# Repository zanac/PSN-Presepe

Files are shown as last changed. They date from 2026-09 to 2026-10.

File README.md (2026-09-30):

# PSN-Presepe

## Demo online Wokwi

▶️ [Apri la simulazione interattiva PSN-Presepe su Wokwi](https://wokwi.com/projects/476035349322038273)

La demo permette di provare direttamente dal browser il ciclo giorno/notte, le strisce RGB, il cielo stellato, OLED e comandi senza hardware reale.

Controller basato su Arduino Mega 2560 per la gestione modulare di un presepe a 12 V.

**Italiano** | [English](README_EN.md)

## Mockup della centralina

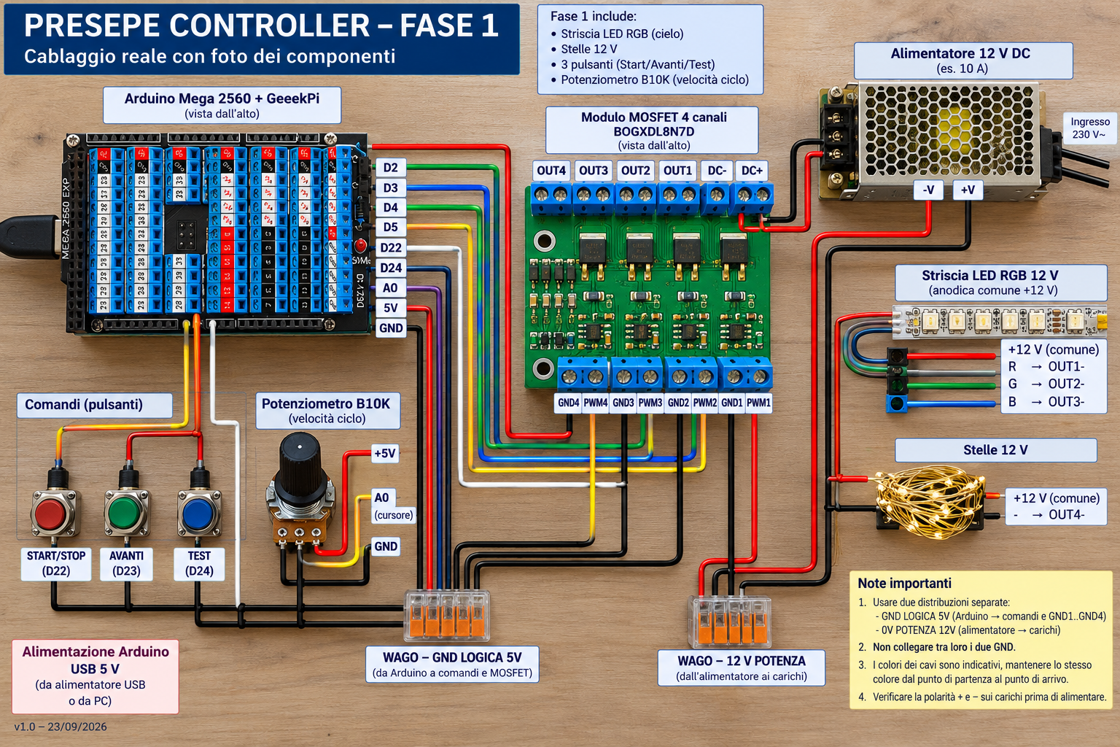
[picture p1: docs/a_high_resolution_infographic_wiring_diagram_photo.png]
Mockup centralina PSN-Presepe


> Mockup concettuale della disposizione della centralina. Per i collegamenti elettrici fare riferimento agli schemi vettoriali presenti nella cartella `docs/`.

## Schema elettrico

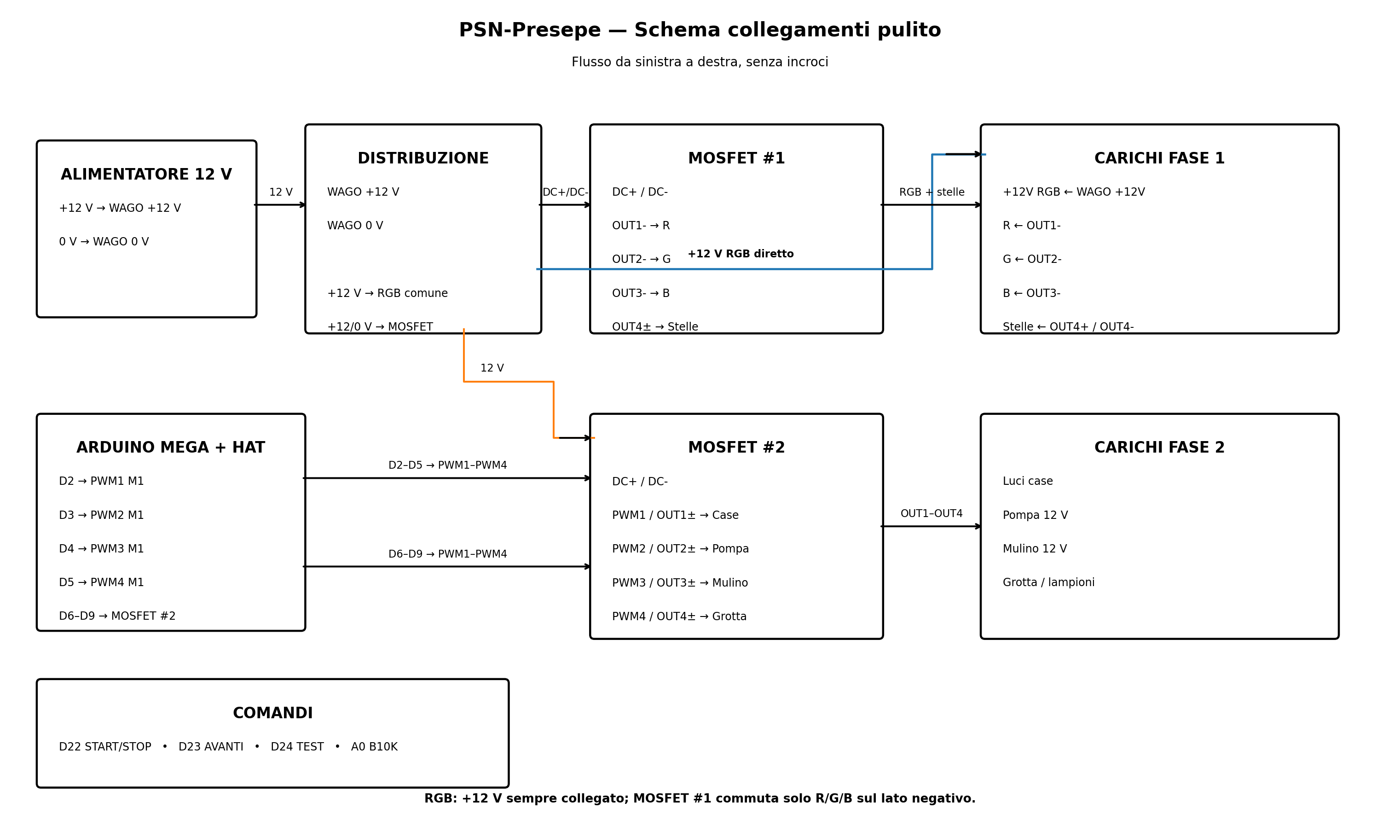
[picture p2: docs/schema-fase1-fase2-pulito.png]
Schema elettrico PSN-Presepe Fase 1 + Fase 2


> Questo è lo **schema di riferimento aggiornato** per il cablaggio. La striscia RGB 12 V è a positivo comune: il +12 V è diretto, mentre R, G e B vengono commutati sul lato negativo dai MOSFET.

## Mappatura hardware attuale

I pin di Arduino **non alimentano direttamente i carichi a 12 V**. Ogni uscita del Mega pilota l'ingresso `PWM` del relativo canale MOSFET. I normali carichi a due fili possono utilizzare la coppia `OUT+` / `OUT-`; la striscia RGB a positivo comune viene invece collegata come indicato qui sotto.

### MOSFET #1 — Cielo RGB

| Arduino Mega | Ingresso MOSFET | Uscita MOSFET | Carico 12 V | Controllo |
|---:|---|---|---|---|
| D2 | PWM1 | OUT1- | Striscia RGB — ritorno R | PWM / dimmerabile |
| D3 | PWM2 | OUT2- | Striscia RGB — ritorno G | PWM / dimmerabile |
| D4 | PWM3 | OUT3- | Striscia RGB — ritorno B | PWM / dimmerabile |
| — | PWM4 | OUT4+ / OUT4- | **Libero** | — |

La striscia RGB è un carico **12 V a positivo comune (anodo comune)**. Il suo unico filo `+12 V` viene collegato direttamente alla distribuzione +12 V protetta/WAGO e rimane sempre alimentato. I tre canali MOSFET commutano invece i ritorni R/G/B sul lato negativo:

```text
+12 V alimentatore ──► F1 CIELO ──┬──► +12 V comune RGB
                                   └──► DC+ MOSFET #1

RGB R ─────────────────────────────────────────► OUT1-
RGB G ─────────────────────────────────────────► OUT2-
RGB B ─────────────────────────────────────────► OUT3-

Mega D2 ───────────────────────────────────────► PWM1  (Rosso)
Mega D3 ───────────────────────────────────────► PWM2  (Verde)
Mega D4 ───────────────────────────────────────► PWM3  (Blu)

0 V alimentatore ──────────────────────────────► DC- MOSFET
```

La striscia RGB **non deve essere cablata come tre carichi indipendenti a due fili**. In questa configurazione `OUT1+`, `OUT2+` e `OUT3+` non sono necessari per la striscia RGB.

### Stelle WS2811 indirizzabili

Le stelle sono ora una stringa **WS2811 12 V da 50 pixel individualmente indirizzabili**. Non passano dal MOSFET: D5 è il segnale DATA.

```text
+12 V alimentatore ──► fusibile/distribuzione ──► WS2811 +12 V
0 V alimentatore ───────────────────────────────► WS2811 GND
Arduino GND ───────────────────────────────────► stesso 0 V comune
Mega D5 ── resistenza 330–470 Ω ──────────────► WS2811 DATA / DIN
```

Con le WS2811 il **GND Arduino deve essere comune allo 0 V dell'alimentatore 12 V**, perché il segnale DATA necessita dello stesso riferimento elettrico. Il Mega continua comunque a essere alimentato a 5 V via USB: il +12 V non deve mai essere collegato ai pin 5 V o I/O di Arduino.

Il firmware può comandare ogni stella separatamente, con luminosità e colore differenti. Dei 50 pixel disponibili, a ogni ciclo vengono selezionate casualmente 20 stelle attive, che compaiono progressivamente durante il crepuscolo e si spengono durante l'alba. Il canale 4 del MOSFET #1 rimane libero.

### MOSFET #3 e #4 — RGB laterali alba/tramonto

Per rendere alba e tramonto più dinamici vengono aggiunte **due strisce RGB analogiche 12 V da 1 m**, indipendenti dalla striscia principale:

| Posizione | Effetto | Mega R/G/B | Modulo |
|---|---|---|---|
| Sinistra | Tramonto | D7 / D11 / D12 | MOSFET #3, CH1–CH3 |
| Destra | Alba | D44 / D45 / D46 | MOSFET #4, CH1–CH3 |

Ogni striscia ha un ramo +12 V protetto dedicato: **F2 ALBA** alimenta sia il +12 V comune della striscia ALBA sia il DC+ del MOSFET #4; **F3 TRAMONTO** alimenta sia il +12 V comune della striscia TRAMONTO sia il DC+ del MOSFET #3. I ritorni R/G/B vanno ai tre OUT- del relativo modulo MOSFET. Il quarto canale di ciascun modulo resta libero. **D8 è dedicato al DATA della seconda catena WS2811 CASETTE.**

Nel firmware le palette RGB sono tarate per ottenere transizioni calde e progressive. Durante il **TRAMONTO** la laterale sinistra parte tenue, raggiunge al 38% un picco arancio chiaro e poi perde gradualmente saturazione; nell'ultimo 18% usa valori R=G=B e si spegne in bianco neutro. Il CIELO parte dalla tonalità lasciata dal GIORNO (210/82/18), diventa progressivamente bianco tenue e si spegne con R=G=B esattamente al picco del TRAMONTO. Durante l'**ALBA** la laterale destra segue una curva analoga, con picco al 38% leggermente meno arancione; il CIELO resta spento fino a quel picco e da lì cresce dolcemente fino alla tonalità iniziale del GIORNO.

### Relè ON/OFF — 4 moduli, 16 uscite

Luci case, pompe, mulino e gli altri carichi che richiedono soltanto ON/OFF vengono gestiti dai **quattro moduli relè 12 V a 4 canali**. I MOSFET restano dedicati ai carichi che richiedono PWM/dimmer.

| Gruppo | Mega | Modulo / ingresso |
|---|---:|---|
| Grp_01_01–Grp_01_04 | D25–D28 | RELÈ #1 IN1–IN4 |
| Grp_02_01–Grp_02_04 | D29–D32 | RELÈ #2 IN1–IN4 |
| Grp_03_01–Grp_03_04 | D33–D36 | RELÈ #3 IN1–IN4 |
| Grp_04_01–Grp_04_04 | D37–D40 | RELÈ #4 IN1–IN4 |

Per ogni scheda: **+12 V di alimentazione del ramo relè → DC+**, **0 V comune → DC-**. Il ramo di alimentazione delle schede relè verrà protetto e dimensionato separatamente quando sarà definita la distribuzione definitiva dei carichi. I morsetti COM/NO/NC restano disponibili per i futuri carichi. Per un carico normalmente spento si useranno normalmente COM + NO; la protezione del carico comandato è distinta da quella che alimenta l'elettronica della scheda relè.

I jumper S1–S4 permettono di scegliere HIGH/LOW trigger. Il firmware gestisce già le 16 uscite nella modalità TEST; nel simulatore viene usata la logica HIGH=ON. Prima del collegamento definitivo dei moduli reali va verificata la posizione dei jumper e, se necessario, impostato `RELE_ACTIVE_LOW` nel firmware.

#### Schedulazione scenografica dei relè

Le accensioni e gli spegnimenti durante il ciclo sono definiti nel firmware dalla tabella `SCHEDULAZIONE_RELE[]`. Ogni evento contiene:

`{ NOME_FASE, NOME_RELE, ACCESO_SPENTO, PERCENTUALE_FASE }`

La percentuale è **relativa alla singola fase**, non all'intero ciclo. Per esempio:

```cpp
const EventoRele SCHEDULAZIONE_RELE[] = {
  { TRAMONTO, Grp_01_03, true,  30 },
  { NOTTE,    Grp_01_03, false, 50 }
};
```

Con questa configurazione `Grp_01_03` si accende al **30% della fase TRAMONTO**, resta acceso durante il resto del tramonto, il crepuscolo e la prima metà della notte, quindi si spegne al **50% della fase NOTTE**.

Lo stato dei relè viene ricostruito dalla posizione corrente del ciclo, quindi rimane coerente anche usando **AVANTI**, pausa/ripresa o modificando la durata con il potenziometro. All'inizio di un nuovo ciclo, prima che siano raggiunti nuovi eventi, i relè partono spenti. In futuro la scenografia ON/OFF può essere modificata semplicemente aggiungendo o cambiando le righe della tabella.

### Display OLED ELEGOO EL-SM-008

Display di stato OLED **0,96 pollici, 128×64, I²C**, alimentazione 3,3–5 V, indirizzo I²C a 7 bit **0x3C**.

| OLED | Arduino Mega 2560 |
|---|---|
| GND | GND |
| VCC | 5 V |
| SDA | D20 / SDA |
| SCL | D21 / SCL |

Il display è **opzionale**: il firmware deve continuare a funzionare normalmente anche se l'OLED non è collegato. All'avvio il software verifica la presenza del display all'indirizzo 0x3C; se non risponde, prosegue senza OLED.

Il firmware usa il display come interfaccia di stato:
- schermata normale: **fase corrente**, percentuale di avanzamento della singola fase, barra grafica, RUN/PAUSA e durata totale del ciclo;
- START/STOP: mette in pausa o riprende il ciclo; in **PAUSA** l'OLED mostra stabilmente fase, percentuale della fase e i valori RGB correnti delle tre strisce; alla ripresa mostra brevemente **RIPRESA**;
- AVANTI: popup **AVANTI** con la nuova fase;
- TEST: feedback **TEST**;
- variazione significativa del B10K: popup **VELOCITA** con la durata effettiva del ciclo in minuti.

I popup durano circa 1,8 secondi e poi il display torna automaticamente alla schermata della fase. L'aggiornamento normale dell'OLED è non bloccante; l'assenza del display non impedisce l'avvio del controllore.

> Nota: sul Mega 2560 l'I²C hardware usa **D20=SDA** e **D21=SCL**. Eventuali esempi che indicano D21/D22 si riferiscono ad altre piattaforme, ad esempio ESP32.

Quando il ciclo viene messo in **PAUSA**, l'OLED mostra stabilmente la fase e la percentuale raggiunta, insieme ai valori RGB correnti delle tre strisce:

- `C R,G,B` = cielo RGB principale;
- `T R,G,B` = RGB laterale TRAMONTO;
- `A R,G,B` = RGB laterale ALBA.

I valori sono quelli logici 0–255 inviati al PWM e permettono di fermare la scena su una tonalità interessante, trascriverla e riutilizzarla successivamente per la taratura dei colori.

### Comandi

| Arduino Mega | Dispositivo | Collegamento |
|---:|---|---|
| D22 | Pulsante START/STOP | D22 ↔ pulsante ↔ GND logica |
| D23 | Pulsante AVANTI | D23 ↔ pulsante ↔ GND logica |
| D24 | Pulsante TEST | D24 ↔ pulsante ↔ GND logica |
| A0 | Potenziometro B10K velocità ciclo | 5 V ↔ esterno, A0 ↔ cursore, GND ↔ esterno |

> **Prova senza potenziometro:** se il potenziometro B10K su A0 viene scollegato, non lasciare A0 flottante: la lettura analogica potrebbe assumere valori casuali e far variare la durata del ciclo. Per una prova stabile, collegare temporaneamente **A0 direttamente a GND**. Il firmware leggerà A0=0, corrispondente alla durata minima del ciclo di **1 minuto**.

I pulsanti utilizzano `INPUT_PULLUP`, quindi non richiedono una resistenza di pull-up esterna. Il GND logico di Arduino viene distribuito tramite WAGO agli ingressi `GND1...GND4` dei MOSFET e ai comandi.

## Sequenza di inizializzazione all'accensione

Prima di iniziare il normale ciclo scenografico, il firmware esegue un **autotest visivo di circa 21,625 secondi**, seguito dalla schermata **PRONTO** per 900 ms. I relè restano spenti e le uscite luminose vengono provate in sequenza:

1. **ALBA** — striscia RGB alba in bianco brillante per circa **4,325 s**;
2. **CIELO** — striscia RGB principale in bianco brillante per circa **4,325 s**;
3. **TRAMONTO** — striscia RGB tramonto in bianco brillante per circa **4,325 s**;
4. **STELLE** — tutti i 50 pixel WS2811 in bianco brillante per circa **4,325 s**;
5. **CASETTE** — seconda catena WS2811 su D8 in bianco brillante per circa **4,325 s**.

La melodia **Astro del ciel** è stata dilatata a circa **21,625 s** per mantenere sincronizzati i cinque passi dell'autotest, la progress bar OLED e la musica. Al termine tutte le uscite vengono spente, compare **PRONTO** per 900 ms e solo dopo viene azzerato il timer del ciclo: il tempo di boot **non fa parte** del ciclo scenografico.

Durante l'intera sequenza l'OLED mostra **Inizializzazione**, il nome dell'uscita in prova, la percentuale complessiva e una progress bar.

## Funzionamento scenografico

Il ciclo automatico usa tre velocità discrete selezionate dal potenziometro: **1, 3 o 5 minuti**. Le fasi non hanno una durata fissa in secondi: occupano una percentuale precisa del ciclo, quindi tutti i tempi scalano linearmente quando si cambia la durata totale.

| Fase | Posizione nel ciclo | Quota ciclo | Ciclo 1 min | Ciclo 3 min | Ciclo 5 min |
|---|---:|---:|---:|---:|---:|
| **GIORNO** | 0–40% | 40% | 24 s | 72 s | 120 s |
| **TRAMONTO** | 40–50% | 10% | 6 s | 18 s | 30 s |
| **CREPUSCOLO** | 50–55% | 5% | 3 s | 9 s | 15 s |
| **NOTTE** | 55–85% | 30% | 18 s | 54 s | 90 s |
| **ALBA** | 85–100% | 15% | 9 s | 27 s | 45 s |

Questa tabella è il riferimento temporale del firmware. Per una durata intermedia, il tempo di ogni fase è semplicemente la percentuale indicata della durata totale.

1. **GIORNO (0–40%)** — stelle e laterali spente. Il CIELO parte caldo (210/82/18), raggiunge progressivamente il bianco pieno al 33% della fase, torna alla tonalità calda entro il 66% e la mantiene fino al TRAMONTO.
2. **TRAMONTO (40–50%)** — la laterale sinistra parte tenue e raggiunge al **38% della fase** un picco arancio chiaro (155/92/16), poi cala perdendo saturazione; nell'ultimo **18%** R=G=B e i tre canali si spengono insieme. Il CIELO parte dalla tonalità finale del GIORNO, si attenua verso un bianco tenue e raggiunge 0/0/0 esattamente al **38%**, cioè al picco della laterale, restando poi spento. Le stelle restano spente.
3. **CREPUSCOLO (50–55%)** — CIELO e laterali sono spenti. Viene generata una nuova disposizione casuale e compaiono progressivamente, una alla volta, **20 stelle scelte tra i 50 pixel disponibili**.
4. **NOTTE (55–85%)** — CIELO e laterali restano completamente spenti. Le 20 stelle rimangono attive con luminosità massime differenti e cicli asincroni individuali di variazione. Il ciclo individuale di ciascuna stella dura circa **6,4–12,2 s**, senza modificare la durata della fase NOTTE.
5. **ALBA (85–100%)** — le stelle iniziano a dissolversi fin dall'inizio. La laterale destra parte con pochissima luce chiara, raggiunge al **38% della fase** un picco arancio chiaro (155/78/22), poi cala perdendo saturazione; nell'ultimo **18%** R=G=B e si spegne in modo simultaneo. Il CIELO resta completamente spento fino al picco dell'ALBA; dal **38%** parte a luminosità molto bassa (10/4/1) e cresce dolcemente fino a 210/82/18, esattamente la tonalità con cui inizia il nuovo GIORNO.

La seconda catena WS2811 **CASETTE su D8** viene inizializzata dal firmware e verificata durante boot e TEST manuale, ma nel normale ciclo scenografico viene mantenuta spenta finché non saranno definite le sue accensioni.

A ogni nuovo CREPUSCOLO viene generata una nuova selezione delle stelle e delle relative luminosità. Il colore delle stelle è **bianco caldo**.

## Manuale di montaggio filo per filo

Questa sezione è il riferimento pratico per il cablaggio. **Non lavorare mai sul circuito con l'alimentatore 230 V collegato.** **Il +12 V non deve mai essere collegato direttamente a un pin del Mega, a 5 V, A0, SDA/SCL o DATA:** il Mega lavora a logica 5 V e i pin I/O non sono ingressi a 12 V. Il Mega è alimentato separatamente via USB 5 V. Il +12 V alimenta soltanto carichi e moduli di potenza. Lo **0 V 12 V e GND Arduino devono essere in comune** per i segnali PWM e per DATA WS2811.

### 1. Distribuzione alimentazione 12 V

> **Cosa significa “+12 V protetto” in questo manuale?**  
> Significa semplicemente che il filo **positivo +12 V è passato attraverso un fusibile prima di raggiungere il carico**. Il fusibile va quindi inserito **sul polo positivo (+12 V)** del ramo da proteggere, non sullo 0 V/negativo.
>
> Esempio: `alimentatore +12 V → fusibile → striscia LED +12 V`.
>
> Se un cavo o un utilizzatore va in cortocircuito, il fusibile di quel ramo interrompe il positivo e protegge soprattutto **cablaggio e connettori** dalla forte corrente che l'alimentatore potrebbe fornire. Quando nelle tabelle seguenti compare la dicitura **“+12 V protetto”**, bisogna quindi leggere: **“+12 V proveniente da un'uscita del portafusibili”**.

Portare il **+12 V** dell'alimentatore all'ingresso positivo del portafusibili/distributore. Ogni uscita del portafusibili avrà il proprio fusibile e alimenterà un singolo ramo: RGB principale, stelle WS2811, RGB tramonto, RGB alba e gli altri carichi. Lo **0 V (negativo)** non passa attraverso questi fusibili di ramo: viene portato alla barra negativa del distributore, se presente, oppure a una morsettiera/WAGO 0 V comune.

```text
ALIMENTATORE 12 V

 +12 V ──► ingresso + portafusibili
                │
                ├─► F1 CIELO ─────► +12 V RGB principale + DC+ MOSFET #1
                ├─► F2 ALBA ──────► +12 V RGB alba + DC+ MOSFET #4
                ├─► F3 TRAMONTO ──► +12 V RGB tramonto + DC+ MOSFET #3
                ├─► F4 STELLE ────► +12 V WS2811
                └─► ... futuri rami protetti (relè/carichi)

  0 V ────────────────────────────► barra negativa / WAGO 0 V comune
                                      ├─► GND/0 V carichi
                                      └─► GND Arduino (riferimento comune)
```

**Scelta progettuale:** CIELO, ALBA, TRAMONTO e STELLE hanno ciascuno un fusibile dedicato. Per le tre strisce RGB, l'uscita del relativo fusibile viene sdoppiata: alimenta sia il +12 V comune della striscia sia il `DC+` della scheda MOSFET che la pilota. Il `DC-` della scheda MOSFET torna allo 0 V comune. Non è previsto un ulteriore fusibile generico separato per le quattro schede MOSFET: la protezione segue il ramo/carico alimentato. Il MOSFET #2, al momento non assegnato a una delle tre RGB, verrà protetto insieme al futuro ramo che utilizzerà.

**Regola pratica per il montaggio:** ogni volta che nel manuale leggi `+12 V protetto`, **non collegare quel filo direttamente al +12 V dell'alimentatore**: collegalo a una delle uscite positive del portafusibili, dopo il relativo fusibile.

| Da | A | Nota |
|---|---|---|
| PSU +12 V | ingresso portafusibili +12 V | cavo dimensionato per la corrente totale |
| PSU 0 V | WAGO/morsettiera 0 V comune | ritorno comune |
| WAGO 0 V | Mega GND | riferimento logico comune |
| WAGO 0 V | DC- MOSFET #1 | ritorno comune modulo CIELO |
| WAGO 0 V | DC- MOSFET #2 | modulo disponibile per futuri carichi |
| WAGO 0 V | DC- MOSFET #3 | ritorno comune modulo TRAMONTO |
| WAGO 0 V | DC- MOSFET #4 | ritorno comune modulo ALBA |
| F1 — CIELO | RGB principale +12 V e DC+ MOSFET #1 | ramo protetto dedicato |
| F2 — ALBA | RGB alba +12 V e DC+ MOSFET #4 | ramo protetto dedicato |
| F3 — TRAMONTO | RGB tramonto +12 V e DC+ MOSFET #3 | ramo protetto dedicato |
| F4 — STELLE | WS2811 +12 V | ramo protetto dedicato |

### 2. MOSFET #1 — RGB principale

| Filo | Da | A |
|---|---|---|
| 1 | Mega D2 | MOSFET #1 PWM1 |
| 2 | Mega GND | MOSFET #1 GND1 |
| 3 | Mega D3 | MOSFET #1 PWM2 |
| 4 | Mega GND | MOSFET #1 GND2 |
| 5 | Mega D4 | MOSFET #1 PWM3 |
| 6 | Mega GND | MOSFET #1 GND3 |
| 7 | F1 — CIELO (+12 V protetto) | RGB principale +12 V |
| 8 | F1 — CIELO (+12 V protetto) | MOSFET #1 DC+ |
| 9 | RGB principale R | MOSFET #1 OUT1- |
| 10 | RGB principale G | MOSFET #1 OUT2- |
| 11 | RGB principale B | MOSFET #1 OUT3- |

Il **DC- del MOSFET #1 deve essere collegato allo 0 V comune**, come indicato nella sezione 1. PWM4/GND4 e OUT4 restano liberi. Prima del cablaggio definitivo verificare sul modulo reale la continuità tra DC+ e OUT+; non assumere la topologia del modulo senza questa verifica.

### 3. Stelle WS2811

| Filo | Da | A |
|---|---|---|
| 12 | F4 — STELLE (+12 V protetto) | WS2811 +12 V |
| 13 | WAGO 0 V comune | WS2811 GND |
| 14 | Mega D5 | resistenza 330–470 Ω |
| 15 | uscita resistenza | WS2811 DATA/DIN |

**Seconda catena WS2811 CASETTE:** il pin **D8** è riservato fin da ora al suo DATA/DIN. La catena avrà alimentazione 12 V e massa comune secondo lo stesso principio delle stelle, ed è ora **inizializzata e pilotata dal firmware per gli autotest di boot e per la modalità TEST manuale**. Durante il normale ciclo scenografico resta spenta: gli effetti delle casette verranno definiti in seguito.

Rispettare la freccia/direzione DATA della stringa. La resistenza va preferibilmente vicino all'ingresso della prima WS2811.

### 4. MOSFET #3 — RGB sinistra / TRAMONTO

| Filo | Da | A |
|---|---|---|
| 16 | Mega D7 | MOSFET #3 PWM1 |
| 17 | Mega GND | MOSFET #3 GND1 |
| 18 | Mega D11 | MOSFET #3 PWM2 |
| 19 | Mega GND | MOSFET #3 GND2 |
| 20 | Mega D12 | MOSFET #3 PWM3 |
| 21 | Mega GND | MOSFET #3 GND3 |
| 22 | F3 — TRAMONTO (+12 V protetto) | RGB sinistra +12 V |
| 23 | F3 — TRAMONTO (+12 V protetto) | MOSFET #3 DC+ |
| 24 | RGB sinistra R | MOSFET #3 OUT1- |
| 25 | RGB sinistra G | MOSFET #3 OUT2- |
| 26 | RGB sinistra B | MOSFET #3 OUT3- |

Il **DC- del MOSFET #3 deve essere collegato allo 0 V comune**, come indicato nella sezione 1. PWM4/GND4 e OUT4 restano liberi.

### 5. MOSFET #4 — RGB destra / ALBA

| Filo | Da | A |
|---|---|---|
| 27 | Mega D44 | MOSFET #4 PWM1 |
| 28 | Mega GND | MOSFET #4 GND1 |
| 29 | Mega D45 | MOSFET #4 PWM2 |
| 30 | Mega GND | MOSFET #4 GND2 |
| 31 | Mega D46 | MOSFET #4 PWM3 |
| 32 | Mega GND | MOSFET #4 GND3 |
| 33 | F2 — ALBA (+12 V protetto) | RGB destra +12 V |
| 34 | F2 — ALBA (+12 V protetto) | MOSFET #4 DC+ |
| 35 | RGB destra R | MOSFET #4 OUT1- |
| 36 | RGB destra G | MOSFET #4 OUT2- |
| 37 | RGB destra B | MOSFET #4 OUT3- |

Il **DC- del MOSFET #4 deve essere collegato allo 0 V comune**, come indicato nella sezione 1. PWM4/GND4 e OUT4 restano liberi. D8 rimane disponibile come uscita PWM di riserva.

### 6. Quattro moduli relè — 16 uscite ON/OFF

I quattro moduli vengono montati e collegati al Mega. Tutti i carichi che richiedono soltanto ON/OFF — casette, pompa, mulino, grotta, lampioni e altri effetti — devono essere assegnati a queste 16 uscite. D6–D9 non sono più riservati a questi carichi.

La nomenclatura standard è `Grp_GG_RR`: `GG` identifica il gruppo/scheda relè (01–04) e `RR` il relè del gruppo (01–04).

| Uscita | Mega | Modulo / ingresso |
|---|---:|---|
| Grp_01_01 | D25 | RELÈ #1 IN1 |
| Grp_01_02 | D26 | RELÈ #1 IN2 |
| Grp_01_03 | D27 | RELÈ #1 IN3 |
| Grp_01_04 | D28 | RELÈ #1 IN4 |
| Grp_02_01 | D29 | RELÈ #2 IN1 |
| Grp_02_02 | D30 | RELÈ #2 IN2 |
| Grp_02_03 | D31 | RELÈ #2 IN3 |
| Grp_02_04 | D32 | RELÈ #2 IN4 |
| Grp_03_01 | D33 | RELÈ #3 IN1 |
| Grp_03_02 | D34 | RELÈ #3 IN2 |
| Grp_03_03 | D35 | RELÈ #3 IN3 |
| Grp_03_04 | D36 | RELÈ #3 IN4 |
| Grp_04_01 | D37 | RELÈ #4 IN1 |
| Grp_04_02 | D38 | RELÈ #4 IN2 |
| Grp_04_03 | D39 | RELÈ #4 IN3 |
| Grp_04_04 | D40 | RELÈ #4 IN4 |

Per **ciascuno dei quattro moduli** collegare anche:

| Da | A |
|---|---|
| +12 V del ramo di alimentazione relè | DC+ |
| 0 V comune | DC- |
| pin Mega indicato sopra | IN1 / IN2 / IN3 / IN4 |

Per ora i morsetti **COM/NO/NC possono rimanere senza carico**. Così tutta la parte di comando `Grp_01_01`–`Grp_04_04` è montata e pronta. In modalità TEST le 16 uscite vengono provate una alla volta, una pressione di TEST per ciascun relè. La sequenza completa comprende **34 test**: CIELO R/G/B, TRAMONTO R/G/B, ALBA R/G/B, STELLE R/G/B, tutte le STELLE in bianco caldo, CASETTE R/G/B, tutte le CASETTE in bianco caldo, TUTTO INSIEME e infine i 16 relè individuali.

Quando assegneremo un carico 12 V normalmente spento, lo schema tipico sarà: **+12 V protetto del carico → COM → NO → positivo carico**, mentre il negativo del carico torna allo **0 V comune**. Il fusibile del carico sarà dimensionato in funzione del carico e del relativo cablaggio.

### 7. Display OLED EL-SM-008

Collegare i quattro fili:

| Filo | Da | A |
|---|---|---|
| OLED 1 | GND | Mega GND |
| OLED 2 | VCC | Mega 5 V |
| OLED 3 | SCL | Mega D21 / SCL |
| OLED 4 | SDA | Mega D20 / SDA |

Indirizzo I²C firmware: **0x3C**. Il display è opzionale: se viene scollegato o dimenticato, il controllore del presepe deve continuare a funzionare.

### 8. Pulsanti

I pulsanti sono momentanei NO. Grazie a INPUT_PULLUP non servono resistenze esterne.

| Filo | Da | A |
|---|---|---|
| 38 | Mega D22 | START/STOP NO |
| 39 | START/STOP COM | Mega GND |
| 40 | Mega D23 | AVANTI NO |
| 41 | AVANTI COM | Mega GND |
| 42 | Mega D24 | TEST NO |
| 43 | TEST COM | Mega GND |

Gli eventuali contatti NC dei pulsanti rimangono scollegati.

### 9. Buzzer piezo passivo opzionale

Il buzzer è un accessorio opzionale. Collegare il positivo/filo rosso a **Mega D6** e il negativo/filo nero a **Mega GND**. Deve essere un buzzer/piezo **passivo**, così il firmware può generare note diverse con `tone()`. Se il buzzer non è collegato, il presepe funziona normalmente senza errori.

Durante il boot il buzzer riproduce **Astro del ciel** fino alla frase **“mite agnello Redentor”**. La melodia viene riprodotta su circa **21,625 s** ed è sincronizzata con i cinque passi **ALBA → CIELO → TRAMONTO → STELLE → CASETTE**: ogni scena dura circa **4,325 s**, così luci, progress bar OLED e ultima nota terminano insieme prima di PRONTO. Al termine il buzzer viene disattivato con `noTone()`.

Il buzzer fornisce anche un feedback acustico semplice durante l'uso: **un unico bip breve e uguale** alla pressione di START/STOP, AVANTI e TEST e quando viene variato il potenziometro. Il feedback è non bloccante e può essere disabilitato impostando `BUZZER_ENABLED=false`. Anche con buzzer fisicamente assente tutto il controller continua a funzionare normalmente.

### 10. Potenziometro B10K

| Filo | Da | A |
|---|---|---|
| 44 | Mega +5 V | estremo B10K |
| 45 | Mega A0 | cursore/centrale B10K |
| 46 | Mega GND | altro estremo B10K |

Se il senso di rotazione risulta invertito rispetto a quello desiderato, scambiare semplicemente i due fili degli estremi; il cursore A0 resta invariato.

### 11. Controllo prima dell'accensione

1. Mega scollegato dalla USB e alimentatore 12 V scollegato dalla rete.
2. Verificare che **+12 V non arrivi mai a 5 V, A0 o a un pin digitale del Mega**.
3. Verificare con multimetro polarità +12 V / 0 V.
4. Verificare la massa comune Mega GND ↔ PSU 0 V.
5. Verificare a circuito spento che **F1 alimenti soltanto CIELO +12 V e DC+ MOSFET #1**, **F2 soltanto ALBA +12 V e DC+ MOSFET #4**, **F3 soltanto TRAMONTO +12 V e DC+ MOSFET #3**, **F4 soltanto WS2811 +12 V**.
6. Verificare che i **DC- dei MOSFET #1, #3 e #4** vadano allo 0 V comune.
7. Verificare che R/G/B delle tre strisce vadano esclusivamente agli **OUT-** corretti e che nessun R/G/B sia collegato direttamente a +12 V o a un pin del Mega.
8. Verificare DATA WS2811: **Mega D5 → resistenza 330–470 Ω → DIN** della prima stella, rispettando la direzione DATA.
9. Prima di inserire i fusibili F1–F4, verificare con il multimetro che non ci sia continuità anomala/cortocircuito tra +12 V protetto e 0 V sui relativi rami.
10. Alla prima accensione inserire **un solo ramo/fusibile alla volta**, iniziando senza carichi di movimento; usare TEST per verificare la corrispondenza tra canale e carico.
11. Solo dopo aver verificato un ramo, passare al successivo.

### Riepilogo pin Mega

| Pin | Funzione |
|---:|---|
| D2 | RGB principale R |
| D3 | RGB principale G |
| D4 | RGB principale B |
| D5 | DATA WS2811 |
| D6 | buzzer piezo passivo opzionale |
| D9–D10 | liberi / riserva |
| D7 | RGB tramonto R |
| D11 | RGB tramonto G |
| D12 | RGB tramonto B |
| D8 | DATA seconda catena WS2811 CASETTE — attiva nei test; effetti scenografici futuri |
| D20 | SDA OLED EL-SM-008 (I²C, opzionale) |
| D21 | SCL OLED EL-SM-008 (I²C, opzionale) |
| D22 | START/STOP |
| D23 | AVANTI |
| D24 | TEST |
| D25–D40 | Grp_01_01–Grp_04_04, quattro moduli relè |
| D44 | RGB alba R |
| D45 | RGB alba G |
| D46 | RGB alba B |
| A0 | potenziometro B10K |

## Firmware

Aprire:

`firmware/PSN-Presepe/PSN-Presepe.ino`

con Arduino IDE e selezionare **Arduino Mega or Mega 2560**.

Il firmware attuale implementa cielo RGB principale, due RGB laterali alba/tramonto, stelle WS2811, seconda catena WS2811 CASETTE per autotest, comandi, OLED, buzzer piezo passivo opzionale e modalità TEST. Il potenziometro A0 è tarato sull'hardware reale (massimo utile circa 680) e, essendo cablato al contrario, seleziona tre durate discrete: raw 454–680 = **1 minuto**, 227–453 = **3 minuti**, 0–226 = **5 minuti**. D9–D10 restano liberi/di riserva; D8 pilota la seconda catena WS2811 CASETTE negli autotest; durante il ciclo normale resta spenta in attesa della futura logica scenografica. I carichi ON/OFF vengono gestiti tramite i 16 relè D25–D40.

## GitHub Actions

Il workflow `.github/workflows/build.yml` può essere avviato manualmente dalla pagina GitHub Actions e parte automaticamente quando viene pubblicata una nuova GitHub Release associata a un tag. Compila il firmware per:

`arduino:avr:mega`

I file compilati vengono pubblicati come artifact della GitHub Action. Per le build avviate da una Release vengono inoltre allegati alla Release il firmware `PSN-Presepe.ino.hex` e il pacchetto `PSN-Presepe-Windows-Portable.zip`.

## Simulazione Wokwi

La simulazione Wokwi riproduce Mega 2560, OLED, pulsanti, potenziometro, buzzer, 50 stelle indirizzabili, 16 uscite relè e le tre strisce RGB. Il file principale è `simulation/diagram.json`.

È disponibile anche `simulation/diagram-no-display.json`, variante dedicata ai test **senza OLED**: è mantenuta allineata a `diagram.json` per tutte le modifiche di cablaggio e componenti che non riguardano il display. Serve a verificare che il firmware continui ad avviarsi e funzionare normalmente quando l'OLED opzionale non è presente.

Per le strisce CIELO, TRAMONTO e ALBA vengono usati i componenti custom `rgb-strip.chip.json` + `rgb-strip.chip.c`: leggono i tre PWM R/G/B e visualizzano una barra del colore risultante. A differenza del normale LED RGB di Wokwi, una striscia a `(0,0,0)` viene mostrata **completamente nera**, quindi nero significa inequivocabilmente **SPENTO**. Il componente gestisce anche PWM 0 e 255 come livelli statici.

I componenti custom sono esclusivamente visuali: non cambiano il firmware e non simulano la potenza elettrica, i MOSFET o i 12 V reali. La documentazione completa della simulazione e dei file da copiare manualmente nel progetto Wokwi è in `simulation/README.md`.

La CI Wokwi rimane per ora opzionale: la normale compilazione GitHub Actions non richiede token o servizi esterni.

## 🧪 Provare PSN-Presepe online con Wokwi — guida passo passo

La simulazione permette di provare il firmware **direttamente dal browser**, senza installare Arduino IDE e senza collegare il Mega reale.

> **Importante:** Wokwi serve soprattutto a verificare firmware, pulsanti, potenziometro, OLED e sequenze. Non simula fedelmente la parte elettrica a 12 V, la potenza dei MOSFET o i carichi reali. I 16 relè sono rappresentati da indicatori.

### 1. Apri un nuovo Arduino Mega

Apri questo indirizzo nel browser:

**https://wokwi.com/projects/new/arduino-mega**

Deve comparire un progetto nuovo con un **Arduino Mega 2560**.

### 2. Copia il firmware

Nel repository PSN-Presepe apri:

`firmware/PSN-Presepe/PSN-Presepe.ino`

Premi il pulsante GitHub per copiare tutto il contenuto del file.

Torna su Wokwi, apri il file **sketch.ino**, cancella tutto quello che contiene e incolla il firmware PSN-Presepe.

> Su Wokwi il file si chiama `sketch.ino`; nel repository si chiama `PSN-Presepe.ino`. È normale.

### 3. Installa le tre librerie

Nel pannello del codice di Wokwi apri **Library Manager** e aggiungi:

```text
Adafruit NeoPixel
Adafruit SSD806
Adafruit GFX Library
```

Wokwi creerà automaticamente il proprio `libraries.txt`.

Nel repository è presente anche `simulation/libraries.txt` come riferimento aggiornato delle librerie necessarie.

### 4. Carica il nostro schema elettrico virtuale

Nel repository scegli uno dei due diagrammi:

- `simulation/diagram.json` per la simulazione completa con OLED;
- `simulation/diagram-no-display.json` per verificare il funzionamento senza display.

Copia **tutto** il contenuto del diagramma scelto.

In Wokwi apri il file **diagram.json**, seleziona tutto, cancella il contenuto esistente e incolla quello del repository.

Dopo pochi istanti il diagramma deve mostrare il Mega e i componenti del PSN-Presepe.

### 5. Avvia

Premi il pulsante verde **▶ Start Simulation**.

Wokwi compilerà il firmware. La prima compilazione può richiedere qualche secondo.

Se usi `simulation/diagram.json`, il Mega virtuale parte e sul display OLED appare l'interfaccia PSN-Presepe. Se usi `simulation/diagram-no-display.json`, il test è corretto quando il firmware continua ad avviarsi e a gestire normalmente autotest, ciclo, RGB, stelle, pulsanti e relè senza OLED.

### 6. Prova il potenziometro

Clicca sul potenziometro **Durata ciclo** e cambiane il valore.

L'OLED deve mostrare temporaneamente **VELOCITA** e la durata del ciclo. Dopo circa 1,8 secondi ritorna alla schermata della fase corrente.

Per fare prove veloci conviene portare il ciclo verso il minimo, circa **1 minuto**.

### 7. Prova i pulsanti

Usa i tre pulsanti virtuali:

| Pulsante | Cosa deve succedere |
|---|---|
| START/STOP | mette in pausa/riprende il ciclo; in PAUSA l'OLED resta sulla schermata con fase, % fase e valori RGB C/T/A; alla ripresa mostra brevemente RIPRESA |
| AVANTI | salta immediatamente alla fase successiva |
| TEST | avvia la sequenza di prova delle uscite |

Con **AVANTI** puoi quindi controllare rapidamente:

`GIORNO → TRAMONTO → CREPUSCOLO → NOTTE → ALBA → GIORNO`

senza aspettare l'intero ciclo.

### 8. Cosa guardare sull'OLED

Questa verifica riguarda la simulazione completa con `simulation/diagram.json`. Durante il funzionamento normale l'OLED deve mostrare:

- nome della fase;
- percentuale **0–100% della fase corrente**;
- barra di avanzamento;
- RUN durante il ciclo; quando è in PAUSA la schermata viene sostituita dai valori RGB delle tre strisce;
- durata impostata del ciclo.

La percentuale riparte da 0 quando cambia fase.

### 9. Apri il Serial Monitor

Durante la simulazione apri **Serial Monitor**.

Il firmware comunica a **115200 baud** e stampa informazioni diagnostiche: fase, percentuale del ciclo, durata, valore A0 e stato RUN/PAUSA.

Se l'OLED virtuale non viene rilevato, il firmware deve comunque continuare a funzionare: è intenzionalmente opzionale.

### 10. Cosa rappresentano i componenti virtuali

Le tre barre custom **CIELO**, **TRAMONTO** e **ALBA** rappresentano visivamente le tre strisce RGB analogiche 12 V reali. Leggono i tre segnali PWM R/G/B e mostrano il colore risultante; **nero significa striscia spenta**. Sono una rappresentazione logica e visiva: Wokwi non simula elettricamente l'alimentazione 12 V, i MOSFET, le correnti o la potenza delle strisce.

La striscia NeoPixel virtuale rappresenta le **50 stelle**. Wokwi usa un componente addressable compatibile per visualizzare l'effetto; nel presepe reale utilizziamo la stringa WS2811 a 12 V con il cablaggio documentato.

Gli indicatori `Grp_01_01`–`Grp_04_04` rappresentano le 16 uscite dei quattro moduli relè collegate a D25–D40. In modalità TEST vengono accese una alla volta dopo i 18 test luminosi (RGB, STELLE, CASETTE e TUTTO INSIEME); dopo `Grp_04_04` la sequenza riparte dal primo test e START esce dalla modalità TEST.

### 11. Se Wokwi dà errore

Controlla nell'ordine:

1. di aver scelto **Arduino Mega 2560**;
2. che `sketch.ino` contenga l'ultima versione del firmware;
3. che siano installate tutte e tre le librerie;
4. che `diagram.json` sia stato copiato integralmente dal file scelto: `simulation/diagram.json` oppure `simulation/diagram-no-display.json`;
5. leggi il messaggio rosso della compilazione o il Serial Monitor.

Se modifichiamo firmware o cablaggio del progetto, anche i file nella cartella `simulation/` devono essere aggiornati insieme.

> **Stelle:** i 50 pixel WS2811 restano fisicamente disponibili, ma a ogni ciclo ne vengono scelte casualmente solo **20**, mantenute a luminosità volutamente bassa. Tutte le 20 stelle attive hanno un proprio ciclo asincrono e variano dolcemente la luminosità; dalla rev037 il ciclo individuale di accensione/spegnimento è raddoppiato (circa 6,4–12,2 s), senza modificare la durata delle fasi del presepe. A ogni nuova notte la disposizione viene rigenerata.

## Nota elettrica

Con l'introduzione delle stelle WS2811, **Arduino GND e lo 0 V dell'alimentatore 12 V sono collegati in comune** per fornire il riferimento al segnale DATA. Il Mega resta alimentato separatamente a 5 V via USB. Prima del cablaggio definitivo verificare con il multimetro la continuità tra `DC+` e gli eventuali `OUT+` utilizzati. Per pompa e mulino devono inoltre essere verificati corrente nominale, corrente di spunto e protezione dei carichi induttivi.

---

By **Vanni Brutto**

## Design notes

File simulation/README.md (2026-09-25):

# Simulazione Wokwi — PSN-Presepe

[Apri Wokwi con Arduino Mega](https://wokwi.com/projects/new/arduino-mega)

La simulazione segue il cablaggio attuale del firmware del branch di lavoro. Per lo sviluppo e i test usare `dev`; `main` resta la versione stabile. Per provarla nel browser, crea un progetto Arduino Mega su Wokwi e copia:
- `simulation/diagram.json` nel diagramma Wokwi;
- in alternativa, `simulation/diagram-no-display.json` per provare il sistema senza OLED;
- `firmware/PSN-Presepe/PSN-Presepe.ino` nel file `sketch.ino`;
- `simulation/rgb-strip.chip.json` e `simulation/rgb-strip.chip.c` nel progetto Wokwi;
- `simulation/libraries.txt` nel Library Manager (`libraries.txt`).

## Variante senza display

Il file `simulation/diagram-no-display.json` è una variante del diagramma principale creata appositamente per verificare il comportamento del controller quando l'OLED non è collegato. Contiene lo stesso hardware simulato di `diagram.json`, ad eccezione del display SSD1306 e dei relativi collegamenti VCC, GND, SDA e SCL.

**Regola di manutenzione:** ogni modifica futura a `simulation/diagram.json` che riguarda cablaggio, controlli, stelle, relè, strisce RGB o altri componenti deve essere riportata anche in `simulation/diagram-no-display.json`. Le modifiche che riguardano esclusivamente l'OLED restano invece solo nel diagramma principale.

Per eseguire il test senza display, copiare il contenuto di `diagram-no-display.json` nel `diagram.json` del progetto Wokwi. Il firmware non va modificato: deve rilevare l'assenza dell'OLED e continuare normalmente con autotest, ciclo scenografico, pulsanti, stelle, RGB e relè.

## Componenti simulati

| Hardware reale | Simulazione | Pin Mega |
|---|---|---|
| RGB cielo tramite MOSFET | barra custom `chip-rgb-strip` | D2/D3/D4 |
| Stelle WS2811 12 V, 50 pixel | striscia NeoPixel WS2812 **5 V solo nel simulatore** | D5 |
| Buzzer piezo passivo opzionale | buzzer Wokwi | D6 |
| RGB tramonto, sinistra | barra custom `chip-rgb-strip` | D7/D11/D12 |
| RGB alba, destra | barra custom `chip-rgb-strip` | D44/D45/D46 |
| OLED ELEGOO EL-SM-008 I²C 0x3C | SSD1306 128×64 | SDA D20 / SCL D21 |
| START/STOP, AVANTI, TEST | 3 pulsanti verso GND | D22/D23/D24 |
| B10K | potenziometro | A0 |
| Quattro schede relè da 4 canali | **16 LED indicatori di pin**, non relè di potenza | D25–D40 |

**Importante:** le 16 uscite relè D25–D40 sono gestite dal firmware e nel simulatore usano HIGH=ON (`RELE_ACTIVE_LOW=false`). Gli indicatori sono denominati `Grp_01_01`–`Grp_04_04`. La modalità TEST le prova singolarmente; inoltre la tabella `SCHEDULAZIONE_RELE[]` gestisce le accensioni durante le fasi. Nel modulo relè reale andranno comunque verificati i selettori HIGH/LOW e la compatibilità degli ingressi prima del collegamento definitivo.

La striscia Wokwi WS2812 è un sostituto visivo: **nel montaggio reale le stelle WS2811 richiedono 12 V protetti, GND comune e una resistenza dati da 330–470 Ω**. Le barre RGB custom Wokwi rappresentano i segnali PWM, non simulano l'alimentazione a 12 V né la portata dei MOSFET. La simulazione non sostituisce la verifica elettrica dei moduli reali.

## Componenti custom RGB Strip

Le tre strisce RGB analogiche non sono più rappresentate dai normali `wokwi-rgb-led`. Questi ultimi, anche quando ricevono RGB `(0,0,0)`, mantengono visibile il corpo chiaro del LED e possono dare l'impressione che una striscia spenta sia bianca.

Per evitare questa ambiguità PSN-Presepe usa un componente Wokwi personalizzato chiamato **RGB Strip**, composto da:

- `simulation/rgb-strip.chip.json`: definizione del componente, dei pin R/G/B e dell'area grafica;
- `simulation/rgb-strip.chip.c`: logica che legge i tre segnali PWM e disegna la barra tramite framebuffer;
- `simulation/diagram.json`: contiene tre istanze `chip-rgb-strip`, una per CIELO, TRAMONTO e ALBA.

Il componente misura il duty-cycle dei tre segnali PWM del Mega e visualizza direttamente il colore risultante. Gestisce anche i casi estremi di `analogWrite(0)` e `analogWrite(255)`, che sull'AVR diventano livelli logici statici. Sotto la zona colorata il framebuffer disegna inoltre una fascia nera con il nome **ALBA**, **CIELO** o **TRAMONTO**; l'istanza seleziona il testo tramite l'attributo numerico `labelId`.

La convenzione visiva è quindi volutamente semplice: **nero = striscia spenta**. Per esempio, durante GIORNO le barre ALBA e TRAMONTO sono nere perché il firmware invia `(0,0,0)`; durante le dissolvenze la barra cambia colore e luminosità seguendo il PWM.

Questo componente è **solo una rappresentazione grafica della simulazione**: non modifica il firmware e non simula elettricamente i MOSFET, l'alimentazione 12 V, le correnti o la potenza delle strisce reali.

### Aggiornare manualmente il progetto Wokwi

Quando cambia soltanto il firmware, è sufficiente ricopiare `PSN-Presepe.ino` in `sketch.ino`. Quando cambia il diagramma o il componente RGB custom, ricopiare anche i relativi file dalla cartella `simulation/`.

Per una nuova simulazione completa servono quindi almeno `sketch.ino`, `diagram.json`, `rgb-strip.chip.json`, `rgb-strip.chip.c` e le librerie indicate in `libraries.txt`.

## Librerie

Il firmware richiede `Adafruit NeoPixel`, `Adafruit SSD1306` e `Adafruit GFX Library`. L'OLED resta opzionale: se non è presente, il programma prosegue.

La GitHub Action `Arduino Mega Build` compila il firmware, ma **non esegue automaticamente la simulazione Wokwi**. Il file `wokwi.toml` è predisposto per un eventuale futuro test automatizzato.

> **Stelle:** i 50 pixel WS2811 restano fisicamente disponibili, ma a ogni ciclo ne vengono scelte casualmente solo **20**, mantenute a luminosità volutamente bassa. Tutte le 20 stelle attive hanno un proprio ciclo asincrono e variano dolcemente la luminosità. A ogni nuova notte la disposizione viene rigenerata.

## Boot simulato

All'avvio il firmware esegue anche in Wokwi l'autotest reale: **ALBA**, **CIELO** e **TRAMONTO** diventano bianchi per circa 4,325 secondi ciascuno, quindi tutti i 50 pixel delle **STELLE** diventano bianchi per circa 4,325 secondi. In contemporanea il buzzer passivo opzionale su **D6** riproduce, a tempo più sostenuto, **Astro del ciel** fino alla frase **“mite agnello Redentor”**. L'autotest visivo viene esteso alla stessa durata della melodia, dividendo ALBA → CIELO → TRAMONTO → STELLE in quattro intervalli uguali, così progress bar, luci e musica terminano insieme prima di PRONTO; se il buzzer reale non è collegato il firmware continua normalmente. L'OLED mostra l'avanzamento complessivo con una progress bar. Finito il test, le uscite vengono spente, l’OLED mostra **PRONTO** per 900 ms e parte da zero il normale ciclo nella fase GIORNO.

## Feedback acustico

Il buzzer opzionale su D6 fornisce un feedback non bloccante molto semplice: **un unico bip breve e uguale** alla pressione di START/STOP, AVANTI e TEST e quando viene variato il potenziometro. Impostando `BUZZER_ENABLED=false` i feedback vengono disabilitati; se il buzzer non è fisicamente collegato il firmware funziona comunque normalmente.

## Comandi e modalità TEST

- **START/STOP** mette in pausa e riprende il ciclo. In pausa l'OLED mostra stabilmente fase, percentuale della fase e i valori RGB correnti: `C` = cielo principale, `T` = tramonto, `A` = alba. Alla ripresa compare brevemente `RIPRESA`.
- **AVANTI** salta all'inizio della fase successiva.
- **TEST** entra nella modalità di collaudo e, a ogni pressione, passa al test successivo. **START/STOP** esce dalla modalità TEST e ripristina il punto del ciclo precedente.

La sequenza TEST attuale comprende **30 passaggi**: CIELO R/G/B, TRAMONTO R/G/B, ALBA R/G/B, STELLE R/G/B su tutti i 50 pixel, tutte le 50 stelle in bianco caldo, tutto insieme e infine i 16 relè `Grp_01_01`–`Grp_04_04` uno alla volta.

## Schedulazione relè

Il firmware contiene `SCHEDULAZIONE_RELE[]`, con eventi nel formato `{ FASE, RELE, STATO, PERCENTUALE_FASE }`. L'esempio attuale accende `Grp_01_03` al 30% di TRAMONTO e lo spegne al 50% di NOTTE. La percentuale è relativa alla singola fase.

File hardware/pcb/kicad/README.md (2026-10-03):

# KiCad PCB — Rev A (routed and validated)

## Production status
The Rev A PCB is routed and validated by the KiCad 10 / Freerouting CI pipeline.

Validated run: **GitHub Actions #65**  
Validated source commit: `4f67314c46dd59c536ec106bf252f43676114665`

Final automated gates:
- board outline: **280 x 170 mm**
- 2 copper layers
- **0 unconnected pads**
- no unexpected DRC categories
- allowed DRC category: `lib_footprint_issues` only
- relay/contact custom clearance gate: **6 mm**
- Mega stackable expansion envelope: PASS
- Mega physical pin mapping: PASS
- Mega mechanical geometry / mandatory assembly BOM: PASS
- external terminal silkscreen labels: PASS
- production Gerber/drill export: PASS
- BOM/CPL export: PASS

## Manufacturing package
The CI artifact `pcb-manufacturing-complete` contains:
- final routed `PSN-Presepe-Mega-FREEROUTED.kicad_pcb`
- `PSN-Presepe-Mega-FREEROUTED.kicad_dru`
- `freerouted-k10.drc.txt`
- `BOM.csv`
- `CPL.csv`
- F.Cu / B.Cu Gerbers
- F.Silkscreen / B.Silkscreen Gerbers
- Edge.Cuts Gerber
- Excellon drill file
- Gerber job file

KiCad accepts `F.Mask` and `B.Mask`, but this board currently has no plottable solder-mask content on those layers, so KiCad omits empty .gts/.gbs files. Empty mask files are not fabricated or synthesized by the workflow.

## Important electrical safety note
The 16 relay COM/NO/NC groups are dry contacts and may be wired externally to mains voltage. The PCB does not distribute phase or neutral. The validated custom rule enforces the designed separation between relay contact routing and SELV circuitry. Final assembly and mains wiring must still use appropriately rated relays, terminals, wire, enclosure, fusing and workmanship.

## Source files
The editable KiCad sources remain in this directory. The manufacturing output is generated deterministically by:
`.github/workflows/pcb-freerouting-k10.yml`.

Do not manufacture from older draft routing artifacts or from the original unrouted PCB alone; use the validated routed manufacturing package produced by the CI pipeline.

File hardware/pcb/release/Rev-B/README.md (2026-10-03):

# PSN-Presepe PCB Manufacturing Release — Rev B

This directory is the validated manufacturing snapshot produced by the KiCad 10 / Freerouting CI pipeline.

Contents:
- final routed KiCad PCB and design rules
- final DRC report
- validated KiCad 10 electrical schematic (.kicad_sch)
- equivalent legacy Eeschema schematic (.sch + cache library)
- schematic ERC report
- BOM.csv
- CPL.csv
- Gerber copper, silkscreen and board outline
- Excellon drill file and Gerber job file
- front/back solder-mask Gerbers (.gts/.gbs), generated from the final routed PCB
- high-resolution technical and manual/documentation PNG previews, plus vector silkscreen SVG

Validation gates include KiCad 10 schematic parsing, schematic-to-PCB connectivity coverage through a KiCad-exported netlist, schematic ERC, 0 unconnected pads, relay/contact 6 mm clearance rule, Mega mechanical/pin/stackable checks, terminal silkscreen checks, production copper-width checks (+12V/GND, +5V_MEGA, RGB loads and relay contacts), solder-mask pad audit, and manufacturing export checks.

Solder-mask Gerbers are mandatory: CI audits F.Mask/B.Mask pad membership on the final post-SES PCB and requires non-empty .gts/.gbs fabrication files.

Generated from GitHub Actions run associated with the parent source commit. Do not edit generated manufacturing files manually.

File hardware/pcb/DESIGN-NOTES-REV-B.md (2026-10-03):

# PSN-Presepe PCB Rev B — design notes

This document consolidates the still-relevant engineering notes from the superseded Rev-A documents. Rev-A files remain available in Git history.

## Architecture
- Arduino Mega 2560 R3 shield, stackable female/pass-through headers mandatory.
- Single external +12 V input. The Mega is supplied through VIN; never apply +12 V to the Mega +5 V rail.
- Mega-generated +5 V is used for low-power logic/peripherals such as OLED and potentiometer.
- Common low-voltage ground is used by Mega, MOSFET stages, ULN2803 drivers and 12 V loads.
- External wiring terminals are on the PCB perimeter with access facing outward.

## Loads and drivers
- Nine IRLZ44N-class MOSFET PWM channels are used for the RGB lighting outputs.
- Gate network: 100 ohm series resistor and 100 kohm pull-down per MOSFET.
- Two ULN2803C devices drive sixteen 12 V relay coils.
- Relay footprint target: Omron G5Q-1 DC12 or an explicitly verified footprint-compatible equivalent.
- Relay contacts are brought to individual COM/NO/NC edge terminals; there is no onboard mains distribution bus.
- WS2811 data outputs are direct logic connections; final pixel count/current is a commissioning input.
- BZ1 is intended for a passive piezo on Mega D6. Use an external/next-revision driver if the selected buzzer exceeds the MCU drive capability.

## Power and thermal notes
- The +12 V rail supplies Mega VIN, relay coils, RGB loads and the WS2811 strings.
- A G5Q-1 12 V coil is budgeted at about 33 mA / 0.4 W; sixteen energized coils are about 0.53 A / 6.4 W before other loads.
- Each ULN2803 can therefore see roughly 0.27 A with all eight assigned relay coils energized; verify package temperature during commissioning.
- Verify the Mega onboard regulator temperature with the actual 12 V VIN and peripheral load.
- IRLZ44N TO-220 tabs are drain-connected. Separate heatsinks must not electrically touch unless suitable insulation is used.
- Final 12 V supply, wiring and upstream fuse must be sized from measured/worst-case RGB + relay + Mega + WS2811 load with engineering margin.

## PCB electrical rules
- +12V/GND: 3 mm production target with only explicitly controlled local neckdowns.
- RGB load returns: 1.5 mm target.
- Relay-contact copper: 2 mm target.
- +5V_MEGA: 0.8 mm target.
- Relay-contact to SELV and inter-relay contact isolation use the project 6 mm target and are checked by final KiCad DRC.
- Same-relay COM/NO/NC terminal geometry is constrained by the selected 5.08 mm terminal pitch and is not represented as a 6 mm pairwise rule.

## Safety scope
The PCB DRC and internal 6 mm rules are engineering checks, not a declaration of regulatory or mains-safety certification. Final suitability depends on the exact relay/terminal parts, PCB material and copper, pollution degree, overvoltage category, altitude, enclosure, fusing/protection and installation practice.

## Source of truth
Rev-B fabrication source, Gerbers, drill files, masks, previews, schematics, ERC/DRC reports and release README are under `hardware/pcb/release/Rev-B/`. The pre-fabrication and commissioning status is tracked in `PREFAB-CHECKLIST-REV-B.md`.

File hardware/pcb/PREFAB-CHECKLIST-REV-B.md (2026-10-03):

# Rev B pre-fabrication checklist

This checklist supersedes the Rev-A checklist for PCB fabrication.
It distinguishes PCB-fabrication blockers from assembly/commissioning checks.

## PCB fabrication — machine verified

- [x] Final board routes with 0 unconnected pads.
- [x] KiCad final DRC has no unexpected violations.
- [x] Relay-contact to SELV and inter-relay isolation rules use the project 6 mm target and are active in final DRC.
- [x] Production copper-width gate passes: +12V/GND 3 mm target with explicitly controlled local neckdowns; RGB returns 1.5 mm; relay contacts 2 mm; +5V_MEGA 0.8 mm.
- [x] F.Mask and B.Mask contain pads and non-empty .gts/.gbs are generated.
- [x] External terminal silkscreen labels are present and visible after assembly.
- [x] All external wiring terminals are on the PCB perimeter with wiring/access side outward.
- [x] Arduino Mega R3 stackable/pass-through header geometry, pin mapping, USB and barrel-jack keepout checks pass.
- [x] High-resolution technical and manual/documentation PNG previews are generated with the manufacturing package.

## Assembly parts — must match footprints before ordering assembled boards

These are not bare-PCB Gerber blockers, but the exact purchased parts must be checked before PCBA/assembly ordering:

- [ ] J1 and J_* terminal blocks: exact manufacturer part, pitch, pin numbering, outward wire-entry and current/voltage rating.
- [ ] JR1..JR16: exact 5.08 mm 3-pole terminal part and rating for the intended external load.
- [ ] K1..K16: exact Omron G5Q-1 DC12 suffix (or footprint-compatible approved equivalent) and contact rating.
- [ ] Q1..Q9: exact IRLZ44N manufacturer variant and selected individual heatsink/insulation arrangement.
- [ ] RV1: exact B10K mechanical part and pin order.
- [ ] BZ1: exact passive piezo part and current. If its required drive exceeds the Mega D6 capability, use an external/next-revision driver; do not substitute an active/high-current buzzer silently.
- [ ] C1: exact 470 uF / 25 V body diameter, lead pitch and polarity.
- [ ] HDR-MEGA-STACK: complete Mega R3 stackable female/pass-through set with long lower tails; mandatory fitted item.

## System commissioning — not a bare-PCB fabrication blocker

- [ ] Record final STELLE and CASETTE WS2811 pixel counts and measured/worst-case current.
- [ ] Size the external 12 V supply, J1 wiring and upstream fuse from RGB + relays + Mega + both WS2811 strings + engineering margin.
- [ ] Verify Mega 5 V regulator temperature with the real OLED/peripheral load when powered from 12 V VIN.
- [ ] Verify ULN2803 package temperature with the maximum simultaneous relay-coil load.
- [ ] Verify MOSFET/heatsink temperature at the real RGB load.
- [ ] Confirm enclosure, pollution/installation conditions and external 230 V wiring practice before using relay contacts at mains voltage. The PCB DRC is not a safety certification.

## Schematic / ERC status

- [x] Rev-B has a real KiCad 10 electrical schematic with instantiated symbols, pins and named electrical nets.
- [x] KiCad 10 successfully opens the schematic and exports its electrical netlist.
- [x] The KiCad-exported schematic netlist covers the connected PCB references and named nets.
- [x] KiCad 10 schematic ERC passes in CI.
- [x] A legacy Eeschema .sch + cache library representation is generated from the same validated PCB connectivity map.
- [x] Modern and legacy schematics plus the ERC report are staged with the Rev-B release package.

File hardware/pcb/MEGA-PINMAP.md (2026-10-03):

# Arduino Mega 2560 — pin map e shield superiore

Questa PCB usa connettori Mega R3 **stackable/pass-through**: un secondo shield può essere montato sopra PSN-Presepe, ma deve rispettare i conflitti elettrici indicati qui.

## Pin occupati da PSN-Presepe

| Pin | Funzione PSN |
|---|---|
| A0 | Potenziometro velocità |
| D2 | CIELO R |
| D3 | CIELO G |
| D4 | CIELO B |
| D5 | STELLE DATA WS2811 |
| D6 | Buzzer |
| D7 | TRAMONTO R |
| D8 | CASETTE DATA WS2811 |
| D11 | TRAMONTO G |
| D12 | TRAMONTO B |
| D20 / SDA | OLED I2C — condivisibile solo con device I2C compatibili e indirizzi non in conflitto |
| D21 / SCL | OLED I2C — condivisibile solo con device I2C compatibili |
| D22 | START |
| D23 | NEXT |
| D24 | TEST |
| D25-D40 | RELAY 1-16 |
| D44 | ALBA R |
| D45 | ALBA G |
| D46 | ALBA B |
| VIN | +12 V alimentazione |

## Pin verificati liberi / protetti dal gate CI

A1, D9, D10, D13, D41, D42, D43 e IOREF non sono collegati a funzioni PSN nella revisione corrente.

Questi pin sono protetti dal controllo CI `check_mega_pinmap.py`: se una modifica PCB li collega accidentalmente, il gate fallisce.

## Regola per un secondo shield

Il pass-through fisico **non implica compatibilità elettrica**. Lo shield superiore non deve pilotare direttamente un pin già usato da PSN. D20/SDA e D21/SCL possono essere condivisi come normale bus I2C se tensione, pull-up, indirizzi e caratteristiche dei dispositivi sono compatibili. Le alimentazioni condivise devono inoltre rispettare i limiti elettrici dell'intero sistema.

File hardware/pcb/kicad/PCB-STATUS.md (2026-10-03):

# PCB CAD status — Rev A

`PSN-Presepe-Mega.kicad_pcb` is the current physical board source.

## Current mechanical state
- outline: **280 x 170 mm** (working coordinates 20..300 x 20..190 mm);
- FR-4 1.6 mm, 2 layers;
- Arduino Mega 2560 carrier/shield architecture;
- 16 Omron G5Q-1 relay footprints in two rows with increased wiring space;
- 16 relay COM/NO/NC terminal blocks on the PCB perimeter;
- all low-voltage terminal blocks on the PCB perimeter with outward wire-entry intent;
- 9 IRLZ44N with a dedicated heatsink/airflow area;
- B10K potentiometer and buzzer onboard;
- terminal-function silkscreen labels included.

## Electrical/netlist state
- 119 named nets;
- 77 electrical/component footprints plus 6 M3 NPTH mounting-hole footprints;
- relay contact mapping verified as G5Q: pins 1/5 coil, 2 COM, 3 NC, 4 NO;
- each JR1..JR16 is independent COM/NO/NC; no mains L/N bus exists on the PCB;
- Mega firmware pin mapping is preserved.

## Routing state
**Routing is intentionally reset to zero.**

A geometric audit of the earlier text-generated draft routing found same-layer crossings between different nets. Those segments were removed rather than presenting an unsafe or unroutable board as complete.

Preliminary net classes are now stored in the KiCad project:
- Default signal: 0.30 mm track / 0.25 mm clearance;
- SELV_POWER: 1.00 mm track / 0.30 mm clearance;
- RELAY_CONTACT: 1.00 mm track / **1.00 mm preliminary clearance**.

The 1.00 mm relay-contact clearance is only a routing placeholder, **not a declaration of 230 V safety compliance**. Final creepage/clearance must be chosen and verified for the actual installation, pollution degree, material and applicable standard.

Final routing must be performed/checked in KiCad with real interactive routing and DRC. In particular:
- SELV and relay-contact routing must remain physically separated;
- no SELV GND plane is allowed under the relay-contact routing area;
- mains-capable contact creepage/clearance must be configured and checked;
- board-edge, pad, via and track clearances must pass DRC.

## Silkscreen
Small connection labels are present near every terminal group:
- power: 12V / GND;
- OLED: 5V / GND / SDA / SCL;
- START, AVANTI, TEST + GND;
- CIELO, TRAMONTO, ALBA: 12V / R / G / B;
- STELLE, CASETTE: 12V / GND / DATA;
- R1..R16: COM / NO / NC.

The final KiCad review must confirm that every label follows the actual terminal wire-entry orientation and does not overlap pads/courtyards.

## Mechanical mounting
Six 3.2 mm NPTH mounting holes are present. Their positions were mechanically rechecked after placement; the simplified center-distance audit reports no other footprint center within 10 mm. Final courtyard/enclosure fit still requires KiCad/physical review.

Final enclosure/standoff fit still requires physical/mechanical review.

## Netlist audit
- exactly 119 global net declarations;
- 119 unique net IDs and names;
- no duplicate, orphan or unused nets;
- no one-pad electrical nets;
- all firmware-required Mega pins are assigned;
- 46 unassigned Mega pads are intentionally unused headers/functions.

## Project portability
The project-local `PSN_Presep_Custom.pretty` library now contains every footprint referenced with the `PSN_Presep_Custom:` prefix in the PCB, including ULN2803 and all dedicated terminal blocks.

A project-local `fp-lib-table` registers that library through `${KIPRJMOD}`, so opening the project does not depend on a separately installed custom footprint library.

Audit result:
- 14 custom footprint names used by the PCB;
- 14 corresponding library footprint files present;
- no board-specific net assignments retained in the extracted library footprints.

## Fabrication status
**DRAFT — NOT FOR FABRICATION.**

No ERC/DRC has been run in a real KiCad environment and no Gerber/Excellon set from this revision is approved for manufacture.

## KiCad 9 real validation checkpoint — 2026-09-30
The board is now successfully parsed by **KiCad 9.0.9** in GitHub Actions (`FULL_LOAD_OK`).

The first real DRC exposed malformed legacy board syntax and placement/footprint defects. Corrected items include:
- KiCad 9 canonical board layer IDs;
- malformed pad/net syntax;
- corrupted Mega VIN/embedded-net block;
- U1/U2 collision with Mega headers;
- C2/C3 collision with ULN2803 pads;
- H2 collision with JR9;
- **Omron G5Q-1 SPDT footprint geometry corrected from the official PCB mounting-hole drawing**.

After these corrections, the latest checked DRC report contains **no remaining shorting-items, electrical clearance, hole-clearance or solder-mask-bridge violations**.

Remaining categories are expected/unresolved work:
- 194 unconnected items because routing is intentionally still absent;
- footprint-library parity/configuration warnings;
- silkscreen text-height/overlap/copper warnings;
- one legacy non-mirrored back-layer text item in the Mega footprint.

This is a major validation checkpoint but **not fabrication approval**. Routing, final isolation strategy, silkscreen cleanup, library parity, final DRC and Gerber inspection are still required.

## Latest real DRC checkpoint

On KiCad 9.0.9 the board parses completely. The latest checked report after the relay-footprint and silkscreen cleanup has:
- **0 shorting-items**;
- **0 electrical-clearance violations**;
- **0 hole-clearance violations**;
- **0 solder-mask-bridge violations**;
- 66 `lib_footprint_mismatch` warnings, caused by embedded/minimal footprint copies differing from library definitions;
- one board-level silkscreen overlap, subsequently corrected in commit `a7ab5dcac050ec48d6e6e1a0c57af99e09669a67`;
- **194 unconnected-item records**, expected because routing is intentionally still zero.

The library-mismatch warnings must be cleaned up before fabrication, but they are not electrical shorts. The 194 unconnected records are not waived: completing and validating routing is the next major PCB task.

## KiCad 9 parser validation
- KiCad 9.0.9 now loads the complete PCB successfully (`FULL_LOAD_OK`).
- Board layer IDs were corrected to KiCad 9 canonical IDs.
- DRC is now executed in GitHub Actions; reports must be interpreted against the exact HEAD commit because placement evolved during parser repair.

## Fabrication gate

CI now treats fabrication readiness explicitly:
- KiCad error-severity DRC violations are parsed separately from unrouted connectivity;
- any real DRC error blocks fabrication;
- any remaining unconnected item also blocks fabrication;
- Gerber/drill export is explicitly conditional on the fabrication gate succeeding;
- the current intentionally unrouted board therefore cannot emit an approved fabrication package.

Routing experiments may run sanity checks with `ALLOW_ROUTING=1`, but this does not bypass DRC, connectivity, electrical invariants, perimeter-terminal constraints, or the final fabrication gate.

## Routing progress checkpoint

The source PCB now contains DRC-reviewed low-risk routing for:
- D22 START;
- D23 NEXT;
- D24 TEST;
- D20 OLED SDA;
- D21 OLED SCL;
- A0 potentiometer wiper.

The current promoted source baseline is **188 unconnected items** (down from 194 initially) with zero error-severity DRC violations at the last validated promotion. Buzzer D6 and WS2811 D5/D8 experiments were deliberately not promoted after candidate DRC exposed crossings/clearance conflicts. Candidate routing is therefore fail-safe: a net can reduce the ratsnest and still be rejected if any new DRC error appears.

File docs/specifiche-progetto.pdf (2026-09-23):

Presepe Controller - specifiche di progetto | Pagina 1

# PRESEPE CONTROLLER

## Specifiche di progetto, architettura, cablaggio Fase 1 e lista della spesa

Obiettivo. Realizzare una centralina modulare per presepe a 12 V DC controllata da Arduino Mega, con ciclo giorno/notte, dissolvenze PWM, stelle, illuminazione scenografica, futuri motori/pompe e comandi manuali. Il progetto deve essere ampliabile e richiedere il meno possibile l'uso del saldatore.
Principio costruttivo: morsetti a vite, WAGO 221, puntalini e cablaggio ordinato. Arduino e logica sono alimentati separatamente via USB 5 V; i carichi sono alimentati a 12 V.

## 1. Architettura generale

Elemento | Scelta / specifica
Controller | Arduino Mega 2560 R3
Breakout | GeeekPi Mega 2560 R3 Terminal Block Breakout Board HAT
Potenza | Moduli MOSFET PWM 4 canali, modello Amazon ASIN B0GXDL8N7D
Numero moduli previsto | Fino a 4 moduli = 16 canali fisici; 15 PWM hardware utilizzabili sul Mega
Tensione carichi | 12 V DC
Alimentazione Mega | USB 5 V separata, consigliata >= 2 A
Distribuzione | WAGO 221 + puntalini su cavo flessibile
Filosofia | Zero/minima saldatura; espansione per fasi

## 2. Mappatura definitiva dei 15 canali PWM

CH | Pin Mega | Funzione prevista
1 | D2 | Cielo RGB - Rosso
2 | D3 | Cielo RGB - Verde
3 | D4 | Cielo RGB - Blu
4 | D5 | Stelle
5 | D6 | Case gruppo A
6 | D7 | Case gruppo B / grotta
7 | D8 | Fuoco
8 | D9 | Lampioni
9 | D10 | Pompa
10 | D11 | Mulino
11 | D12 | Movimento 1
12 | D13 | Movimento 2
13 | D44 | Espansione
14 | D45 | Espansione
15 | D46 | Espansione

Il quarto canale del quarto modulo MOSFET resta fisicamente disponibile, ma il Mega dispone di 15 uscite PWM hardware.

## 3. Fase 1 - carichi e comandi

Cielo RGB: striscia analogica RGB 5050, 12 V, 5 m, 60 LED/m, anodo comune +12 V. Stima di progetto circa 14,4 W/m, quindi circa 72 W e 6 A al massimo teorico con bianco pieno. Per il montaggio definitivo è prevista alimentazione/iniezione adeguata alle estremità.
Stelle: DFRobot Star Series LED Strand, 100 LED warm white, 12 V, circa 10 m, assorbimento molto ridotto (ordine di 0,2 A). Un singolo canale PWM.
Comandi: tre pulsanti momentanei normalmente aperti: START/STOP su D22, AVANTI su D23, TEST su D24. Collegamento verso GND con INPUT_PULLUP, quindi senza resistenze esterne.
Velocità ciclo: potenziometro lineare B10K: un estremo al +5 V del Mega, cursore centrale ad A0, altro estremo a GND logica. Non deve mai essere collegato ai 12 V.

## 4. Cablaggio logico del primo modulo MOSFET

Arduino Mega | Modulo MOSFET
D2 | PWM1
D3 | PWM2
D4 | PWM3
D5 | PWM4

GND logica: un solo filo parte dal GND del Mega verso un WAGO di distribuzione. Da questo WAGO partono i collegamenti verso GND1, GND2, GND3 e GND4 del modulo MOSFET, i tre pulsanti e il GND del potenziometro. Importante: il modulo fotografato presenta ingressi separati PWMn/GNDn e optoisolatori. Nel progetto attuale il GND logico Arduino viene mantenuto separato dallo 0 V di potenza 12 V. Non unire i due domini senza una verifica specifica del modulo.

## 5. Alimentazione e lato potenza

L'alimentatore 12 V alimenta esclusivamente i carichi e il lato potenza dei MOSFET: +12 V -> DC+ del modulo; 0 V -> DC- del modulo. Il Mega viene alimentato separatamente tramite USB 5 V.
Dalle fotografie del modulo risultano morsetti OUT1+/OUT1-, OUT2+/OUT2-, OUT3+/OUT3-, OUT4+/OUT4- e DC+/DC-. Prima del cablaggio definitivo della striscia RGB va verificata con multimetro la continuità tra DC+ e i vari OUTn+. È probabile che siano comuni, ma questa verifica deve precedere l'alimentazione.
Assumendo confermata la topologia low-side: R RGB -> OUT1-, G -> OUT2-, B -> OUT3-, negativo stelle -> OUT4-. Il comune +12 V della RGB e il positivo delle stelle vanno alla distribuzione +12 V / OUT+ secondo quanto confermato dalla misura.

## 6. Logica HIGH/LOW e PWM invertito

Il firmware contiene la costante PWM_INVERTED. Cambiare questa impostazione non richiede alcuna modifica al cablaggio. Se la polarità logica reale del modulo è opposta a quella attesa, il risultato è semplicemente ON/OFF e dissolvenze invertiti.
Primo collaudo consigliato: utilizzare un piccolo carico LED 12 V sul CH1. Con PWM_INVERTED=false, verificare che analogWrite(D2,0) produca OFF e analogWrite(D2,255) produca ON. Se accade il contrario, impostare PWM_INVERTED=true. Questa verifica va completata prima di collegare pompa, mulino o altri carichi meccanici.

## 7. Funzionamento software

Il programma è progettato con millis() e macchina a stati, evitando delay() durante il normale funzionamento. Il ciclo scenografico previsto è: GIORNO -> TRAMONTO -> CREPUSCOLO -> NOTTE -> ALBA -> GIORNO. START/STOP mette in pausa e riprende il ciclo mantenendo il punto corrente. AVANTI passa alla fase successiva. TEST prova i canali; nella Fase 1 esegue la prova di R, G, B e stelle. Il B10K regola la durata complessiva del ciclo indicativamente fra 5 e 60 minuti.
Firmware di riferimento attuale: PresepeController_Fase1_v2.ino. Debug seriale a 115200 baud.

## 8. Fasi di sviluppo

Fase | Contenuto
1 | Mega + breakout + primo MOSFET + cielo RGB + stelle + START/STOP + AVANTI + TEST + B10K
2 | Secondo MOSFET: case, grotta, fuoco, lampioni
3 | Pompa, mulino e movimenti; protezioni per carichi induttivi
4 | Quarto modulo / canali di espansione
Finale | Dimensionamento definitivo alimentatore, fusibili, distribuzione, cablaggio e pannello

## 9. Lista della spesa

Q.tà | Componente | Note
1 | Arduino Mega 2560 R3 | Controller principale
1 | GeeekPi Mega 2560 Terminal Block Breakout Board HAT Morsetti a vite; zero saldature
1 ora / fino a 4 Modulo MOSFET PWM 4CH ASIN B0GXDL8N7D | | Primo modulo in Fase 1; fino a quattro nel progetto finale
1 | Alimentatore USB 5 V >= 2 A | Alimentazione separata del Mega
1 | Alimentatore 12 V DC | Potenza finale da dimensionare dopo inventario completo carichi
1 | Striscia RGB analogica 5050 12 V, 5 m, 60 LED/m | Cielo; circa 6 A teorici a pieno bianco
1 | DFRobot Star Series 100 Warm White, 12 V | Stelle
3 | Pulsanti panel-mount momentanei NO | START/STOP, AVANTI, TEST; preferibilmente morsetti a vite
1 | Potenziometro lineare B10K panel-mount | Preferibilmente morsetti a vite
Vari | WAGO 221 | Distribuzione GND logica e 12 V; un conduttore per porta
1 kit | Puntalini/ferrule + pinza crimpatrice | Per cavo flessibile nei morsetti
Vari | Cavo flessibile | Indicativamente 0,5 mm² segnali/piccoli carichi; sezione maggiore per distribuzione potenza
Da definire | Portafusibili/fusibili | Da dimensionare nella fase finale
Da definire | Protezione carichi induttivi | Flyback/soluzione adeguata per pompa, motori, relè/solenoidi se presenti

## 10. Dimensionamento elettrico provvisorio

Carichi già noti: RGB circa 6 A massimi teorici + stelle circa 0,2 A, quindi circa 6,2 A a 12 V prima di aggiungere case, lampioni, fuoco, pompa, mulino e movimenti. Per questo non viene ancora fissata la potenza definitiva dell'alimentatore. La linea RGB da 5 m è il carico principale della Fase 1. Con correnti di questo ordine bisogna dimensionare correttamente cavi, morsetti, distribuzione e fusibile; nel montaggio definitivo è prevista un'alimentazione della striscia adeguatamente distribuita per limitare cadute di tensione.

## 11. Checklist prima dell'accensione

- Verificare con multimetro la continuità DC+ <-> OUT1+/OUT2+/OUT3+/OUT4+ del modulo MOSFET.
- Verificare polarità +12 V e 0 V prima di collegare i carichi.
- Tenere separati GND LOGICA Arduino e 0 V POTENZA 12 V secondo l'architettura attuale.
- Provare prima un solo canale con piccolo carico LED 12 V.
- Determinare PWM_INVERTED prima di collegare carichi meccanici.
- Non collegare mai 12 V a pin Mega, A0, pulsanti o potenziometro.
- Per il test iniziale della RGB evitare di partire direttamente con condizioni gravose se distribuzione/cavi non sono ancora definitivi.

Stato del progetto: architettura generale definita; Fase 1 pronta per assemblaggio e collaudo. Le caratteristiche elettriche non ancora verificate fisicamente (in particolare la relazione fra OUTn+ e DC+) restano esplicitamente da misurare prima del cablaggio definitivo.

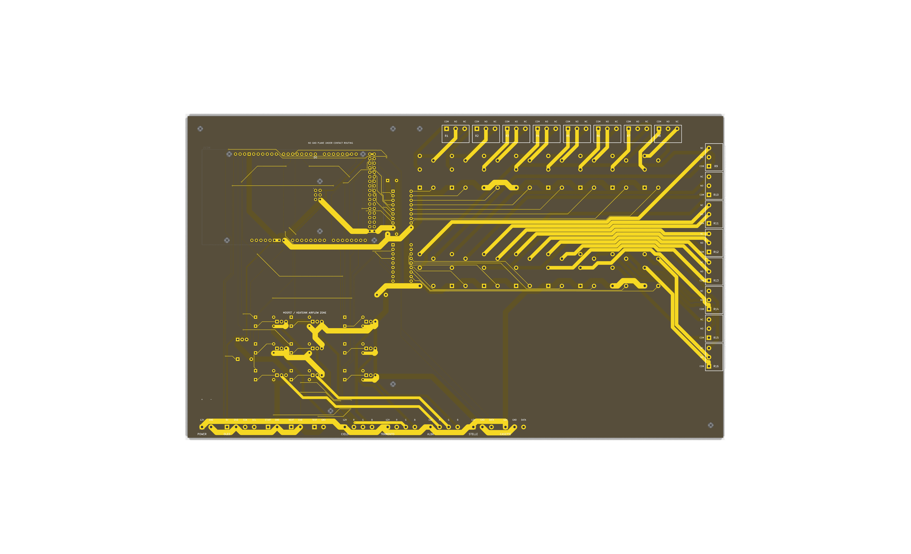
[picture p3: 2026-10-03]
hardware/pcb/release/Rev-B/previews/PSN-Presepe-RevB-technical.png

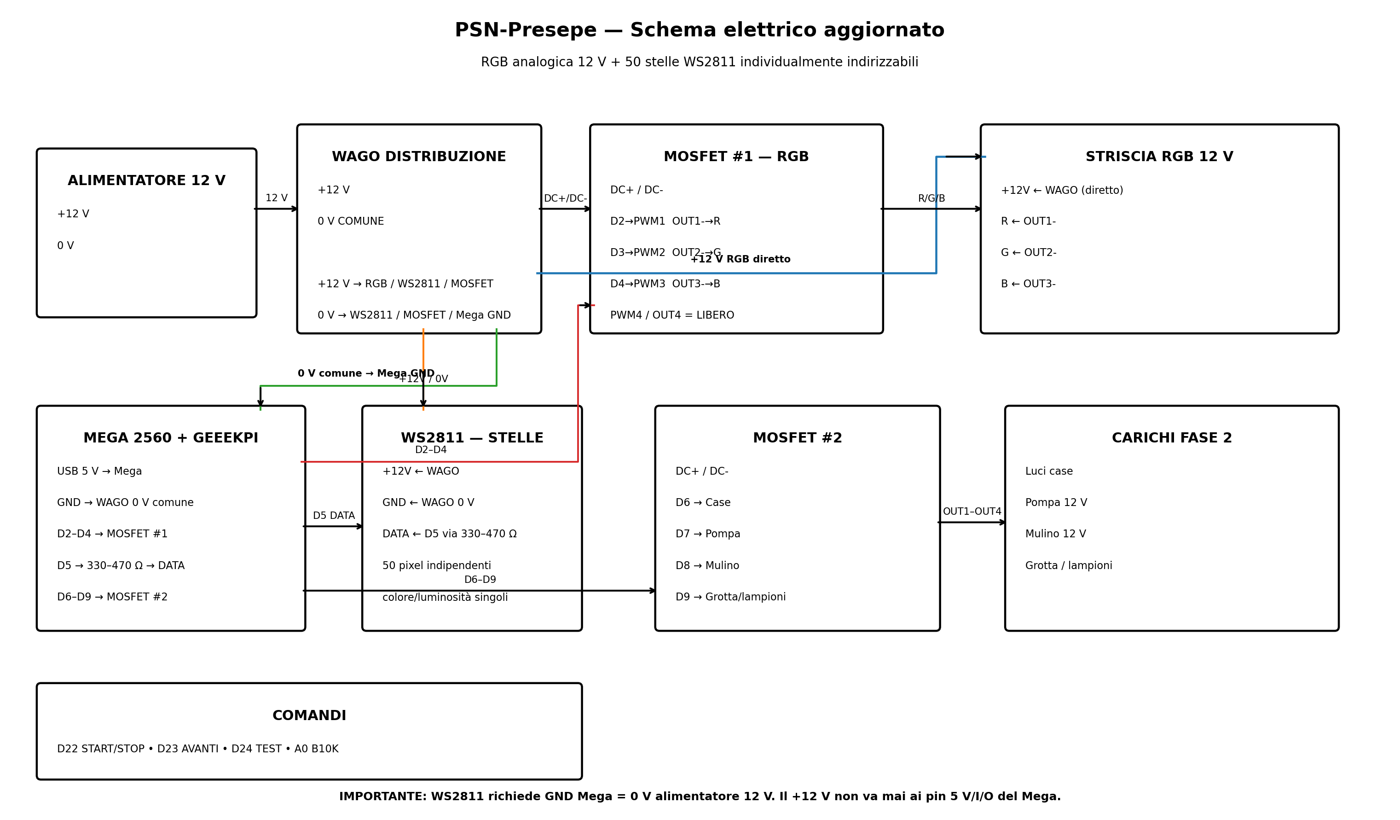
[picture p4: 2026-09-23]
docs/schema-fase1-fase2-ws2811.png

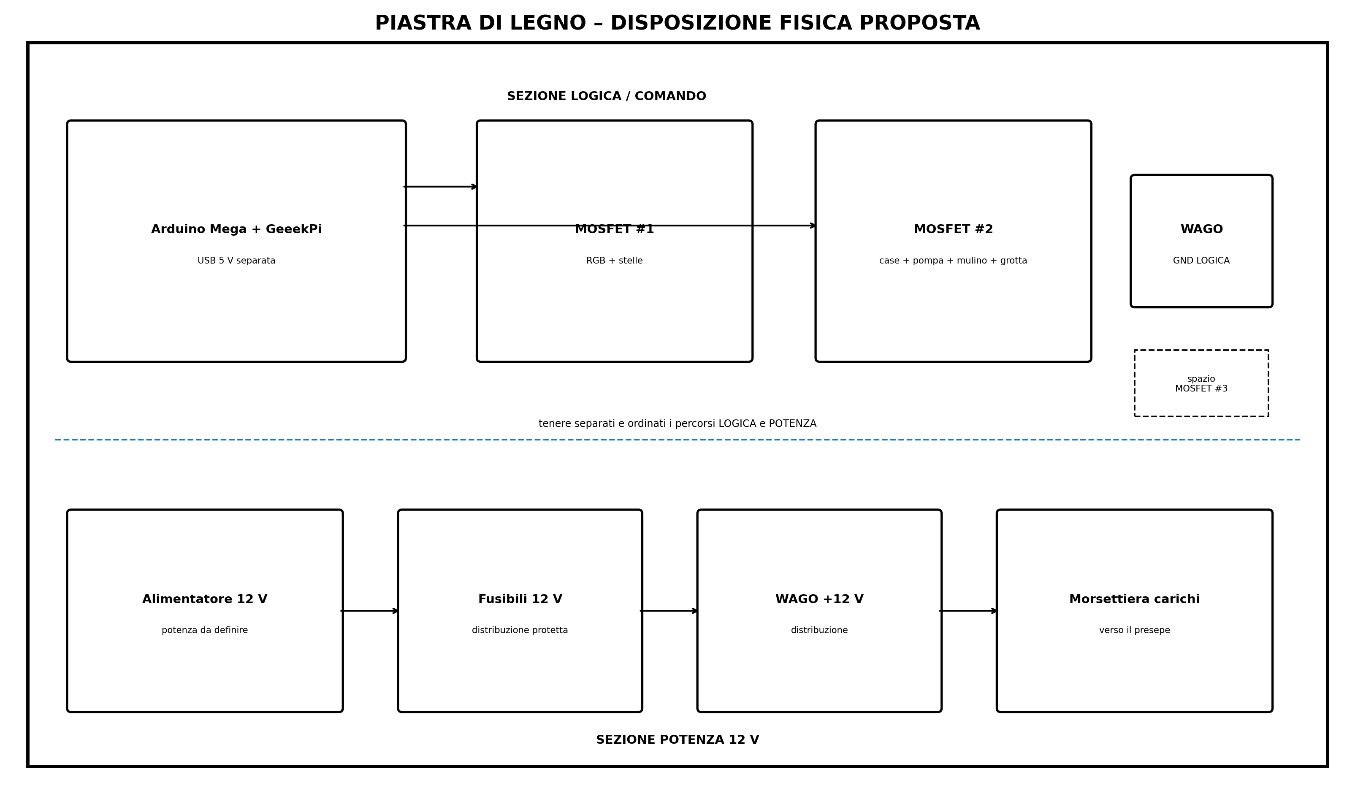
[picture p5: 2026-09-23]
docs/disposizione-su-legno.png

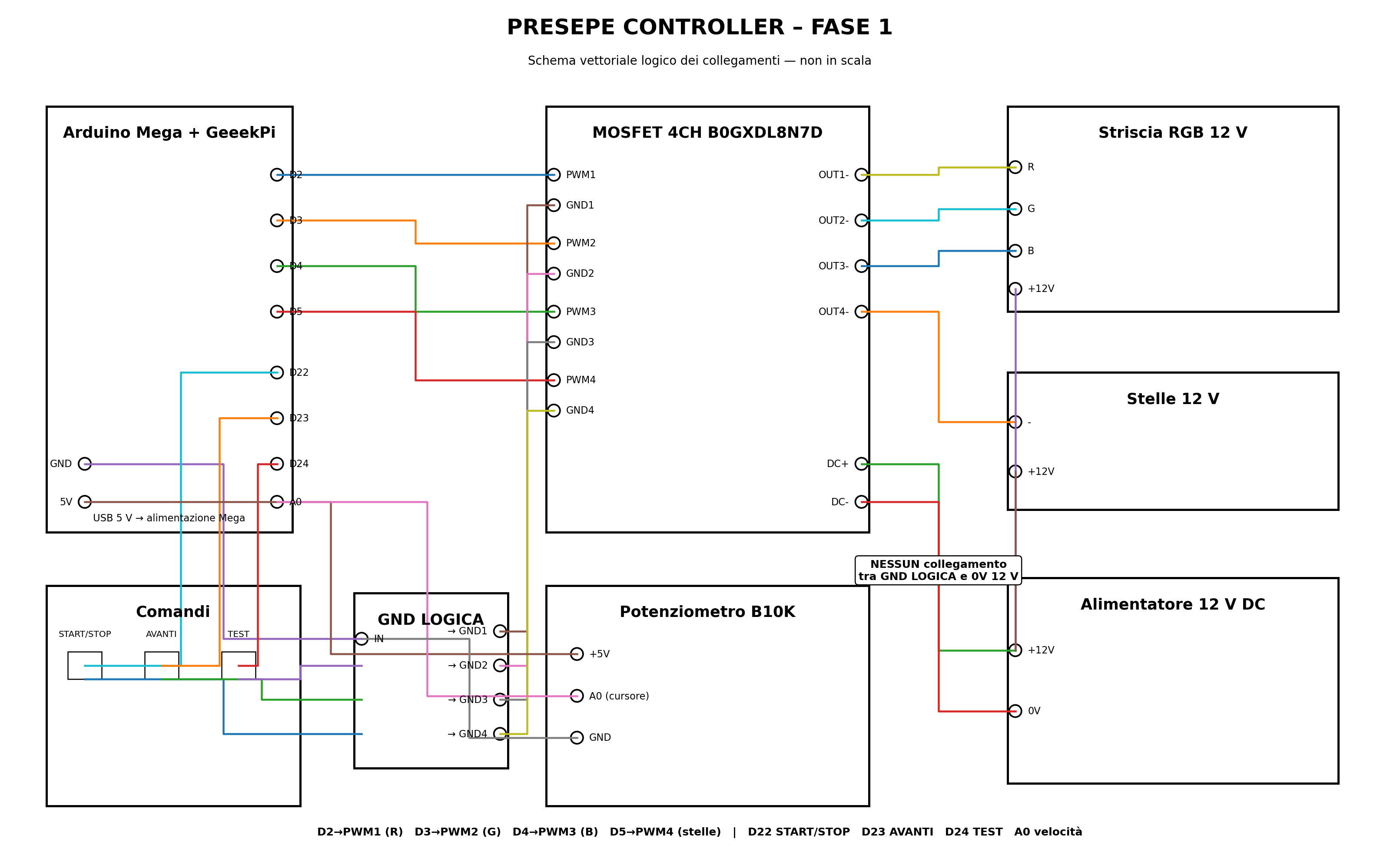
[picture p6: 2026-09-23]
docs/schema-fase1.png

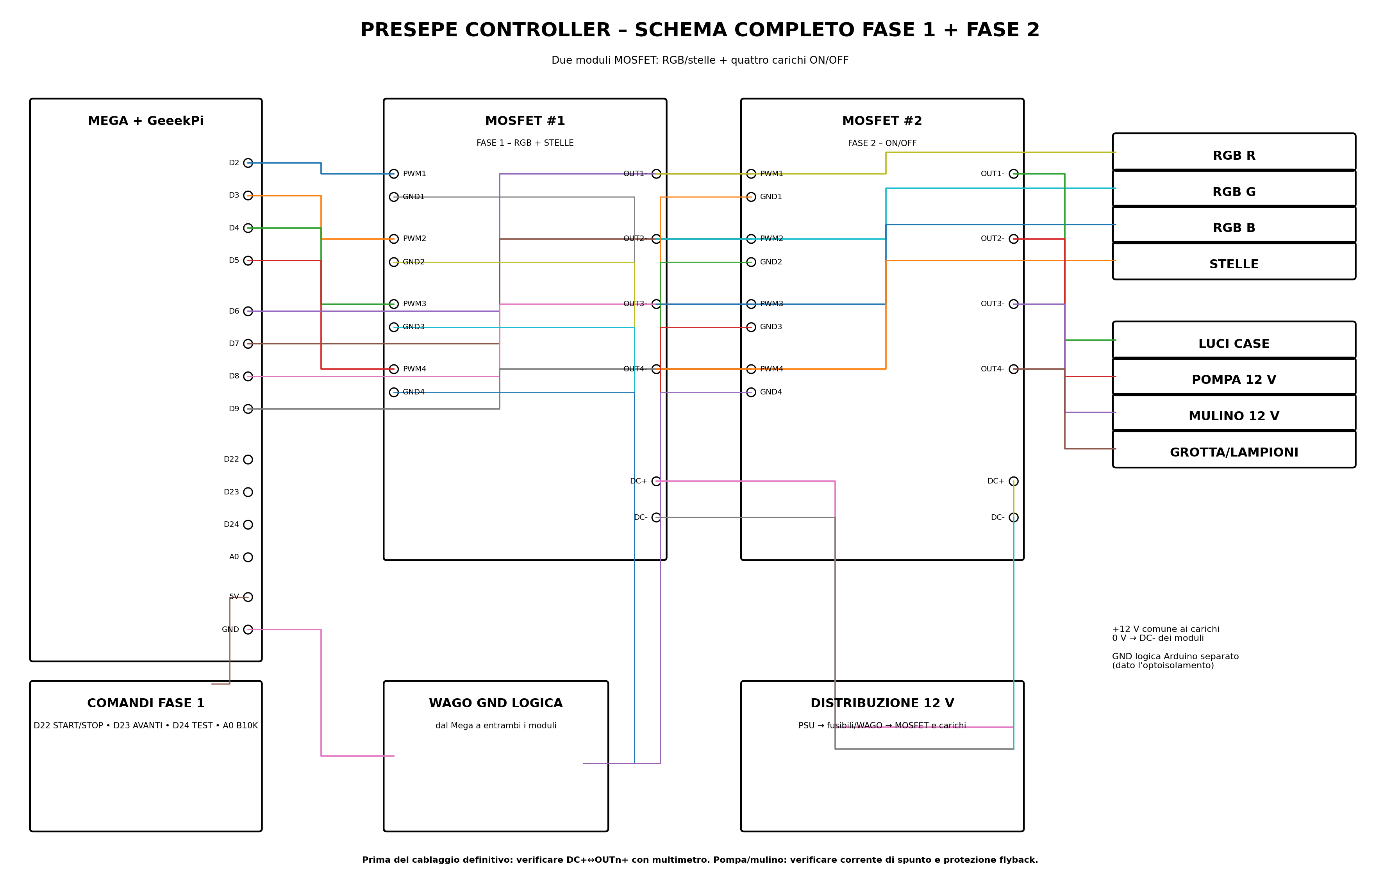
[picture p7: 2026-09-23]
docs/schema-fase1-fase2.png

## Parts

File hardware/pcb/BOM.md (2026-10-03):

# PSN-Presepe PCB assembly BOM

This file contains assembly-critical mechanical items that are not optional.

| Item | Qty | Description | Assembly status | Notes |
|---|---:|---|---|---|
| HDR-MEGA-STACK | 1 set | Arduino Mega 2560 R3 complete stackable/pass-through female header set | FITTED / MANDATORY | Female sockets on top, long male tails below; includes all Mega R3 shield header groups and the non-standard D7-D8 spacing. Do not substitute closed female headers. |

## Stack construction

`future shield -> PSN-Presepe PCB -> Arduino Mega 2560 R3`

`HDR-MEGA-STACK` must be installed and soldered when the PCB is assembled. It is never DNI/DNP.

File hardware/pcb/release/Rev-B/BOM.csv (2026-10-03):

Designator | Qty | Value | Footprint | Layer
BZ1 | 1 | PASSIVE_BUZZER_D6 | Buzzer_12x9.5RM7.6 | Top
C1 | 1 | 470uF_25V_RELAY_BULK | C_Radial_D10.0mm_H12.5mm_P5.00mm | Top
C2 | 1 | 100nF_ULN1 | C_Disc_D5.0mm_W2.5mm_P5.00mm | Top
C3 | 1 | 100nF_ULN2 | C_Disc_D5.0mm_W2.5mm_P5.00mm | Top
H1 | 1 | M3_NPTH | MountingHole_1 | Top
H2 | 1 | M3_NPTH | MountingHole_2 | Top
H3 | 1 | M3_NPTH | MountingHole_3 | Top
H4 | 1 | M3_NPTH | MountingHole_4 | Top
H5 | 1 | M3_NPTH | MountingHole_5 | Top
H6 | 1 | M3_NPTH | MountingHole_6 | Top
J1 | 1 | 12V_IN | 12V_IN | Top
JR1 | 1 | COM_NO_NC | TerminalBlock_Phoenix_MKDS-1.5-3-5.08 | Top
JR10 | 1 | COM_NO_NC | TerminalBlock_Phoenix_MKDS-1.5-3-5.08 | Top
JR11 | 1 | COM_NO_NC | TerminalBlock_Phoenix_MKDS-1.5-3-5.08 | Top
JR12 | 1 | COM_NO_NC | TerminalBlock_Phoenix_MKDS-1.5-3-5.08 | Top
JR13 | 1 | COM_NO_NC | TerminalBlock_Phoenix_MKDS-1.5-3-5.08 | Top
JR14 | 1 | COM_NO_NC | TerminalBlock_Phoenix_MKDS-1.5-3-5.08 | Top
JR15 | 1 | COM_NO_NC | TerminalBlock_Phoenix_MKDS-1.5-3-5.08 | Top
JR16 | 1 | COM_NO_NC | TerminalBlock_Phoenix_MKDS-1.5-3-5.08 | Top
JR2 | 1 | COM_NO_NC | TerminalBlock_Phoenix_MKDS-1.5-3-5.08 | Top
JR3 | 1 | COM_NO_NC | TerminalBlock_Phoenix_MKDS-1.5-3-5.08 | Top
JR4 | 1 | COM_NO_NC | TerminalBlock_Phoenix_MKDS-1.5-3-5.08 | Top
JR5 | 1 | COM_NO_NC | TerminalBlock_Phoenix_MKDS-1.5-3-5.08 | Top
JR6 | 1 | COM_NO_NC | TerminalBlock_Phoenix_MKDS-1.5-3-5.08 | Top
JR7 | 1 | COM_NO_NC | TerminalBlock_Phoenix_MKDS-1.5-3-5.08 | Top
JR8 | 1 | COM_NO_NC | TerminalBlock_Phoenix_MKDS-1.5-3-5.08 | Top
JR9 | 1 | COM_NO_NC | TerminalBlock_Phoenix_MKDS-1.5-3-5.08 | Top
J_ALBA | 1 | ALBA_12V_R_G_B | ALBA_12V_R_G_B | Top
J_CASETTE | 1 | CASETTE_12V_GND_DATA | CASETTE_12V_GND_DATA | Top
J_CIELO | 1 | CIELO_12V_R_G_B | CIELO_12V_R_G_B | Top
J_NEXT | 1 | NEXT_GND | NEXT_GND | Top
J_OLED | 1 | OLED_5V_GND_SDA_SCL | OLED_5V_GND_SDA_SCL | Top
J_START | 1 | START_GND | START_GND | Top
J_STELLE | 1 | STELLE_12V_GND_DATA | STELLE_12V_GND_DATA | Top
J_TEST | 1 | TEST_GND | TEST_GND | Top
J_TRAMONTO | 1 | TRAMONTO_12V_R_G_B | TRAMONTO_12V_R_G_B | Top
K1 | 1 | G5Q-1_DC12 | Relay_Omron_G5Q-1_SPDT | Top
K10 | 1 | G5Q-1_DC12 | Relay_Omron_G5Q-1_SPDT | Top
K11 | 1 | G5Q-1_DC12 | Relay_Omron_G5Q-1_SPDT | Top
K12 | 1 | G5Q-1_DC12 | Relay_Omron_G5Q-1_SPDT | Top
K13 | 1 | G5Q-1_DC12 | Relay_Omron_G5Q-1_SPDT | Top
K14 | 1 | G5Q-1_DC12 | Relay_Omron_G5Q-1_SPDT | Top
K15 | 1 | G5Q-1_DC12 | Relay_Omron_G5Q-1_SPDT | Top
K16 | 1 | G5Q-1_DC12 | Relay_Omron_G5Q-1_SPDT | Top
K2 | 1 | G5Q-1_DC12 | Relay_Omron_G5Q-1_SPDT | Top
K3 | 1 | G5Q-1_DC12 | Relay_Omron_G5Q-1_SPDT | Top
K4 | 1 | G5Q-1_DC12 | Relay_Omron_G5Q-1_SPDT | Top
K5 | 1 | G5Q-1_DC12 | Relay_Omron_G5Q-1_SPDT | Top
K6 | 1 | G5Q-1_DC12 | Relay_Omron_G5Q-1_SPDT | Top
K7 | 1 | G5Q-1_DC12 | Relay_Omron_G5Q-1_SPDT | Top
K8 | 1 | G5Q-1_DC12 | Relay_Omron_G5Q-1_SPDT | Top
K9 | 1 | G5Q-1_DC12 | Relay_Omron_G5Q-1_SPDT | Top
MCU1 | 1 | Arduino_Mega2560_R3_Shield | Arduino_Mega2560_R3_Shield | Top
Q1 | 1 | IRLZ44N_CIELO_R | TO-220-3_Vertical | Top
Q2 | 1 | IRLZ44N_CIELO_G | TO-220-3_Vertical | Top
Q3 | 1 | IRLZ44N_CIELO_B | TO-220-3_Vertical | Top
Q4 | 1 | IRLZ44N_TRAM_R | TO-220-3_Vertical | Top
Q5 | 1 | IRLZ44N_TRAM_G | TO-220-3_Vertical | Top
Q6 | 1 | IRLZ44N_TRAM_B | TO-220-3_Vertical | Top
Q7 | 1 | IRLZ44N_ALBA_R | TO-220-3_Vertical | Top
Q8 | 1 | IRLZ44N_ALBA_G | TO-220-3_Vertical | Top
Q9 | 1 | IRLZ44N_ALBA_B | TO-220-3_Vertical | Top
RG1 | 1 | 100R_GATE | R_Axial_DIN0207_L6.3mm_D2.5mm_P10.16mm_Horizontal | Top
RG2 | 1 | 100R_GATE | R_Axial_DIN0207_L6.3mm_D2.5mm_P10.16mm_Horizontal | Top
RG3 | 1 | 100R_GATE | R_Axial_DIN0207_L6.3mm_D2.5mm_P10.16mm_Horizontal | Top
RG4 | 1 | 100R_GATE | R_Axial_DIN0207_L6.3mm_D2.5mm_P10.16mm_Horizontal | Top
RG5 | 1 | 100R_GATE | R_Axial_DIN0207_L6.3mm_D2.5mm_P10.16mm_Horizontal | Top
RG6 | 1 | 100R_GATE | R_Axial_DIN0207_L6.3mm_D2.5mm_P10.16mm_Horizontal | Top
RG7 | 1 | 100R_GATE | R_Axial_DIN0207_L6.3mm_D2.5mm_P10.16mm_Horizontal | Top
RG8 | 1 | 100R_GATE | R_Axial_DIN0207_L6.3mm_D2.5mm_P10.16mm_Horizontal | Top
RG9 | 1 | 100R_GATE | R_Axial_DIN0207_L6.3mm_D2.5mm_P10.16mm_Horizontal | Top
RPD1 | 1 | 100K_PULLDOWN | R_Axial_DIN0207_L6.3mm_D2.5mm_P10.16mm_Horizontal | Top
RPD2 | 1 | 100K_PULLDOWN | R_Axial_DIN0207_L6.3mm_D2.5mm_P10.16mm_Horizontal | Top
RPD3 | 1 | 100K_PULLDOWN | R_Axial_DIN0207_L6.3mm_D2.5mm_P10.16mm_Horizontal | Top
RPD4 | 1 | 100K_PULLDOWN | R_Axial_DIN0207_L6.3mm_D2.5mm_P10.16mm_Horizontal | Top
RPD5 | 1 | 100K_PULLDOWN | R_Axial_DIN0207_L6.3mm_D2.5mm_P10.16mm_Horizontal | Top
RPD6 | 1 | 100K_PULLDOWN | R_Axial_DIN0207_L6.3mm_D2.5mm_P10.16mm_Horizontal | Top
RPD7 | 1 | 100K_PULLDOWN | R_Axial_DIN0207_L6.3mm_D2.5mm_P10.16mm_Horizontal | Top
RPD8 | 1 | 100K_PULLDOWN | R_Axial_DIN0207_L6.3mm_D2.5mm_P10.16mm_Horizontal | Top
RPD9 | 1 | 100K_PULLDOWN | R_Axial_DIN0207_L6.3mm_D2.5mm_P10.16mm_Horizontal | Top
RV1 | 1 | B10K | Potentiometer_Alps_RK09K_Single_Horizontal | Top
U1 | 1 | ULN2803C | ULN2803C_DIP18 | Top
U2 | 1 | ULN2803C | ULN2803C_DIP18 | Top

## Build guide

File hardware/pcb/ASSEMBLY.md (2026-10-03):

# PCB assembly requirements

## Arduino Mega 2560 R3 stacking headers

The PSN-Presepe PCB is designed as a **stackable Arduino Mega 2560 R3 shield**.

The PCB assembly order must include the complete set of Arduino Mega R3 headers as **female stackable / pass-through headers**, soldered to the PSN-Presepe PCB.

Requirements:
- Arduino Mega 2560 R3 shield pin geometry, including the non-standard D7-D8 spacing.
- Female sockets accessible from the **top side** for a future additional shield.
- Long male tails on the **bottom side** to plug into the Arduino Mega 2560 R3.
- Through-hole soldered assembly.
- Do **not** substitute closed/non-stackable female headers.
- Keep the full Mega stacking envelope free of components; CI enforces this with `hardware/pcb/tools/check_mega_stackable.py`.

Assembly intent:

`future shield -> PSN-Presepe PCB -> Arduino Mega 2560 R3`

These headers are mandatory fitted components when ordering an assembled PCB, not DNI/DNP parts.

## Terminal silkscreen — mandatory production requirement

Every external terminal block must have readable **F.SilkS labels for each individual pole**, positioned beside the corresponding terminal. Net names existing only in the KiCad pad/net data are not sufficient.

Required labels include:
- Power input: `+12V`, `GND`.
- RGB outputs (CIELO, TRAMONTO, ALBA): `+12V`, `R`, `G`, `B` plus connector/function name.
- WS2811 outputs (STELLE, CASETTE): `+12V`, `GND`, `DATA` plus connector/function name.
- OLED: `+5V`, `GND`, `SDA`, `SCL`.
- Buttons: signal/function (`START`, `NEXT`, `TEST`) and `GND`.
- Every relay terminal JR1..JR16: `COM`, `NO`, `NC`, with relay/channel identification.

Gerber/manufacturing release is blocked until a CI/mechanical check confirms these terminal labels are present on silkscreen and do not overlap pads, board edges, or other critical markings.

### Silkscreen visibility after assembly

Terminal and connection labels must remain readable on the fully assembled PCB. A label passing copper/pad DRC is not sufficient.

- Do not place functional connection labels underneath relays, terminal blocks, capacitors, heatsinks, headers, or any other fitted component body.
- Keep labels outside the physical body/courtyard of fitted components wherever possible.
- Place terminal pole labels on the wiring/access side of the terminal block so they remain visible while connecting wires.
- Relay `COM / NO / NC` and channel identification must remain visible with the relay and terminal block installed.
- The production release must include a mechanical/silkscreen visibility review of the fully populated board before Gerber approval.

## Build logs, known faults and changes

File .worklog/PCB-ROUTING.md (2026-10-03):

# PCB routing worklog

This file is the persistent restart checkpoint for long PCB-routing sessions.

## Resume contract

1. Read this file first.
2. Fetch current `dev` and `wip/pcb-routing` HEADs before changing anything.
3. Experiments and partially validated routes stay on `wip/pcb-routing`.
4. Prefix intermediate save points with `WIP:`.
5. Update this file after every meaningful experiment with commit SHA, CI run, DRC result and next action.
6. Only routes proven by KiCad DRC and connectivity reduction may be promoted to `dev`.
7. Never force-update `dev`; fetch fresh files before every write.
8. The production/fabrication gate remains on `dev`.

## Checkpoint — 2026-10-01

- WIP branch created from dev SHA: `d364e63c1caabbaacaafa5bef12728aee291bc30`.
- PCB parser: OK under KiCad 9.
- Fabrication source has progressed beyond the original zero-track draft; current dev history reports a validated baseline around 169 unconnected items before the latest K2 experiment.
- K1 coil route was promoted after KiCad validation in commit `f73b14ec0d2dd4d86b28c541501978ca8525dc9`.
- Rotated relay pad-coordinate audit was corrected in commit `097a0a13692466858d6e51f11b53f1ddc64de986`.
- Latest CI run checked: `36821407171`, commit `d364e63c1caabbaacaafa5bef12728aee291bc30`, title “Test K2 coil-low route from corrected relay geometry”; conclusion: failure. This is the immediate investigation target.
- Earlier low-risk D22/D23/D24 candidate demonstrated the non-destructive candidate method but its first geometry had shorts/crossings; do not reuse that obsolete path blindly.
- Critical invariants remain: relay G5Q corrected pinout; all terminals on perimeter; MOSFET heatsink spacing; no unreviewed copper zones; explicit fabrication gate.

## Immediate next actions

1. Read CI logs/artifact for run 36821407171.
2. Determine whether K2 candidate failure is DRC geometry, connectivity, or workflow/gate-only failure.
3. Correct K2 only on this WIP branch and commit as `WIP: ...`.
4. Re-run/inspect KiCad validation.
5. If clean and it reduces unconnected count exactly as expected, record the successful SHA/run here.
6. Promote the proven change to `dev` as a clean commit, then advance/rebase this WIP branch from fresh dev.
7. Continue K3..K16 one small validated route group at a time.

## Durable design blockers before fabrication

- Exact J1 part/current rating.
- Exact terminal-block wire-entry direction and ratings.
- Final WS2811 current budget.
- Mega VIN regulator thermal check.
- PCB-level relay-contact creepage/clearance review for actual external voltage/environment.
- Footprint-library mismatch cleanup.

## Investigation: K2 candidate

Run `36821407171` was inspected in full. The K2 route itself is clean:
- baseline: 169 unconnected;
- candidate: 168 unconnected;
- reduction: exactly 1;
- candidate non-routing warnings: 66 library mismatches, same as baseline;
- critical/detail DRC blocks: 0;
- no shorts, clearance errors, crossings or mask bridges.

The workflow failed because `compare_unconnected.py` in `CANDIDATE_MODE=baseline` exits 1 when connectivity changes. That behavior is wrong for an experimental route whose purpose is to improve connectivity. **Do not change the K2 geometry; fix the comparator/gate semantics first.**

## Checkpoint protocol now active

The WIP branch has isolated CI enabled. Long routing work should be split into these durable stages:
1. `WIP: plan <net/group>` — record baseline and intended geometry;
2. `WIP: test <net/group>` — candidate generator/geometry only;
3. `WIP: validate <net/group>` — record exact KiCad run ID, DRC categories and connectivity delta;
4. `WIP: ready <net/group>` — only after zero new critical DRC categories;
5. promote the proven PCB change to fresh `dev`, then checkpoint the new dev SHA here.

A restart therefore needs only this file, the two branch HEADs and the most recent referenced CI run/artifact.

## READY: K2 coil-low

WIP CI run `36821692685` on SHA `287e144fcbafdfa45f7119e9d23096b7108b5a8e` revalidated the K2 candidate after comparator repair:
- source baseline: 169 unconnected;
- K2 candidate: 168 unconnected;
- connectivity reduction: 1;
- non-routing warnings: 66 baseline / 66 candidate;
- critical DRC categories: none;
- detail blocks: 0.

K2 geometry is therefore READY for clean promotion to fresh `dev`. Candidate path: U1.17 (145.16,64.54) -> (148,66.5) -> (173,66.5) -> (175.62,64) -> K2.5 (175.62,60), F.Cu 0.30 mm, net 37 RELAY2_COIL_LOW.

## Promoted baseline

K2 was promoted to `dev` in commit `d8761dd1bf4adc2f0b2304a1835ebe33a3bc4dd1`; sanity whitelist updated in `a728d711a275e50bf1e7d17cdb207a2b63e460ca`. Stable validation workflow run `36821946903` confirmed the official PCB at **168 unconnected items, 0 error-severity DRC violations, no critical geometry/electrical categories**. Stable and experimental CI were then separated (`ae11ce53...`, `727d91d4...`).

Next routing target: K3 / `RELAY3_COIL_LOW` from U1 output to K3 coil pad, using the corrected Y-down rotated relay geometry. Start from fresh dev HEAD, not from the old K2 candidate generator.

## Checkpoint K5 — 2026-10-01

- K5 / `RELAY5_COIL_LOW` net 40 promoted in `9d1b02622b19cd3b372162aa1dcf989d9fa6d91c`.
- Sanity allow-list updated in `76e252d9f4eabce3c5dec292bf02dfb8ce4fabec`.
- Stable KiCad 9.0.9 run: `36824507731`.
- Official baseline: **165 unconnected items**.
- Error-severity DRC violations: **0**.
- Critical geometry/electrical categories: **none**.
- Next target: K6 / `RELAY6_COIL_LOW`, net 41, U1 pad13 -> K6 pad5.

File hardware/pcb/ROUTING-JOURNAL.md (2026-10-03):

# PCB Routing Journal — Rev A

Persistent restart/checkpoint log for long autonomous routing sessions on branch `dev`.

## Rules

- Never route directly from an unverified idea into the production PCB.
- Build one small candidate net/group at a time in a temporary copy.
- Run KiCad 9 DRC on the candidate.
- Promote only candidates with zero error-severity DRC violations and a real reduction in unconnected items.
- After promotion, commit immediately and record the new baseline here.
- Keep relay-contact routing and high-current/pour work for dedicated reviewed phases.
- Gerber export remains blocked until the fabrication gate sees zero DRC errors and zero unconnected items.

## Current verified baseline

- Branch: `dev`
- Baseline HEAD when this checkpoint was written: `3f41e3e98e11786a8fc51d589adb8a157fd18042`
- KiCad: 9.0.9 in GitHub Actions
- Source PCB routed segments: at least 109
- Copper zones: 0
- Error-severity DRC violations: **0**
- Unconnected items: **160**
- Full-report non-routing warnings: 66 `lib_footprint_mismatch`
- Fabrication status: **BLOCKED / NOT FOR FABRICATION**

## Verified/promoted routing groups

The source sanity allow-list currently contains these routed net IDs:

- 14, 15: OLED SDA/SCL
- 16, 17, 18: START/NEXT/TEST
- 19: A0 potentiometer signal
- 36, 37, 38, 39, 40, 41, 42, 43, 44: relay coil-low K1/K2/K3/K4/K5/K6/K7/K8/K9
- 63..71: local MOSFET gate nodes

These nets are considered source-PCB routing checkpoints because they were promoted only after candidate DRC validation.

## Current experiment

Next candidate: `RELAY10_COIL_LOW`, net 45, U2 pad17 -> K10 pad5.

Generator:
`hardware/pcb/tools/make_route_candidate.py`

Important: re-read the production PCB and generator from fresh `dev` HEAD before editing. Concurrent commits have occurred during previous sessions.

## Restart procedure

1. Fetch `dev` HEAD.
2. Read this journal.
3. Check latest `pcb-kicad.yml` run.
4. Confirm production baseline with `pcb_sanity.py` and KiCad DRC.
5. Inspect the current candidate generator.
6. Run/inspect candidate DRC.
7. If clean and connectivity improves, promote only that candidate net.
8. Commit the promotion.
9. Update sanity approved-net allow-list.
10. Update this journal baseline and next candidate.

## Historical milestones

- Initial production board: 0 segments / 194 unconnected.
- First naive D22/D23/D24 candidate reduced connectivity but created shorts/crossings; it was rejected and never promoted.
- Candidate workflow was moved into the KiCad project directory so project footprint libraries are resolved correctly.
- Low-risk routing was then promoted incrementally rather than as one large text-generated route set.
- Current verified production baseline: 166 unconnected, zero error-severity DRC violations.

## Do not infer

A red GitHub Actions run does not automatically mean routing failed. While the board is incomplete, the final fabrication gate intentionally exits non-zero for remaining unconnected items. Always inspect the DRC counts and candidate-specific steps/logs.

## Checkpoint K5 — 2026-10-01

- K5 / `RELAY5_COIL_LOW` net 40 promoted in `9d1b02622b19cd3b372162aa1dcf989d9fa6d91c`.
- Sanity allow-list updated in `76e252d9f4eabce3c5dec292bf02dfb8ce4fabec`.
- Stable KiCad 9.0.9 run: `36824507731`.
- Official baseline: **165 unconnected items**.
- Error-severity DRC violations: **0**.
- Critical geometry/electrical categories: **none**.
- Next target: K6 / `RELAY6_COIL_LOW`, net 41, U1 pad13 -> K6 pad5.

## Checkpoint K6 — 2026-10-01

- K6 / `RELAY6_COIL_LOW` net 41 candidate passed dedicated route validation on run `36824635074`.
- K6 route promoted in `ca01fe1fb9f8d1e2e33b271d4be57d3ba8253dcc`.
- Sanity allow-list updated in `ca7565f4aed8d7d69ef1fb77e9e3324dc0286b88`.
- Candidate reduced connectivity from **165 → 164 unconnected items** with zero error-severity DRC violations.
- Next target: K7 / `RELAY7_COIL_LOW`, net 42, U1 pad12 -> K7 pad5.

## Checkpoint K7 — 2026-10-01

- K7 / `RELAY7_COIL_LOW` net 42 candidate passed dedicated route validation on run `36824895407` and Routing Lab `36824895370`.
- K7 route promoted in `6b68a10e4f4a674b6cefec46b93f88035723c038`.
- Sanity allow-list updated in `3f41e3e98e11786a8fc51d589adb8a157fd18042`.
- Candidate improved connectivity with zero error-severity DRC violations; official baseline is now **163 unconnected items**.
- Next target: K8 / `RELAY8_COIL_LOW`, net 43, U1 pad11 -> K8 pad5.

## Checkpoint K8/K9 — 2026-10-01

- K8 / net 43 passed Route Candidate run `36825163253` and Routing Lab `36825163240`; promoted in `92b51d9ade2f77bdfbd14e6c32fc90ccd81dfb0e`, sanity-approved in `da995d58895f32e03e9aa645983017897bd52724`.
- K9 / net 44 passed Route Candidate run `36825298968` and Routing Lab `36825299003`; promoted in `eb7ac805b9a549f9871fbe4db3625000b6ec9203`, sanity-approved in `6cfd658603feee9aa6f601e6d1489f433ac8953b`.
- K1-K8 first coil-low bank is complete; second bank routing has started with K9.
- Official connectivity after K9 is **161 unconnected items**.
- Next target: K10 / `RELAY10_COIL_LOW`, net 45, U2 pad17 -> K10 pad5; candidate commit `f355ad399eab761c4f565e3a53219743873418e0`.

## K10 rejected candidate — 2026-10-01

- Candidate `f355ad399eab761c4f565e3a53219743873418e0` reduced connectivity **161 -> 160**, but was correctly rejected by Route Candidate run `36825569934`.
- DRC found K10 trace crossing K9 coil trace and touching K9 contact pads (`R9_NC`, `R9_COM`): 1 tracks_crossing, 2 shorting_items, 3 solder_mask_bridge.
- Nothing from this failed candidate was promoted to the production PCB.
- Revised K10 candidate `838e61b3dc6f0e53eba087d159820d8b42295f62` routes around the left/bottom of K9 and must pass the full candidate gate before promotion.

## Checkpoint K10 — 2026-10-01

- Revised K10 candidate `838e61b3dc6f0e53eba087d159820d8b42295f62` passed Route Candidate run `36825827075` with all gate steps successful.
- K10 / net 45 promoted in `f3bcda32516b89d19843643708845e0119bd251b` and sanity-approved in `2ea98eb2c71bd09bed03ded318b039c09c0754bc`.
- Official connectivity after K10: **160 unconnected items**.
- K11 / net 46 candidate prepared in `0c90ef05d92acda60cadc32e994b2534617a294a` using a lower corridor below K10.

## K11 rejected candidate — 2026-10-01

- Candidate `0c90ef05d92acda60cadc32e994b2534617a294a` reduced **160 -> 159** but was rejected by run `36825931693` for one `tracks_crossing` only.
- Exact crossing: K11 first segment from U2.16 intersects K10 vertical segment at `(142.0,96.5..118.0)`; no shorts were reported.
- Revised K11 candidate `68718816b2a38c29f8d96a4ba7934758ab69114c` exits U2 to the right and uses y=122 lower corridor.

## K11 second rejected candidate — 2026-10-01

- Candidate `68718816b2a38c29f8d96a4ba7934758ab69114c` again reduced **160 -> 159**, but run `36826094970` rejected it for exactly one `tracks_crossing`.
- Existing K9/K10 F.Cu corridors constrain a clean same-layer escape from U2.16.
- Third candidate `3022cabc0e84f851c72c524990f2827ac1d8dc3d` uses a controlled B.Cu crossover with two vias, returning to F.Cu near K11. It must pass full DRC before promotion.

## K11 third rejected candidate — 2026-10-01

- B.Cu candidate `3022cabc0e84f851c72c524990f2827ac1d8dc3d` reduced **160 -> 159** but run `36826462548` rejected it.
- Exact errors from candidate artifact: F.Cu escape crossed K9 coil route; B.Cu diagonal crossed K10 COM pad `(168.0,104.84)`, causing one short and one solder-mask bridge.
- DRC artifact also confirms actual lower relay coordinates K11..K16; no further coordinate extrapolation is needed.
- Fourth candidate `ffd9058b0c0dce627d6f4b7ceda41f36553ee566` drops to B.Cu beside U2 and uses y=124 below the relay row before returning beside K11 coil pad.

## K11 fourth rejected candidate — 2026-10-01

- Candidate `ffd9058b0c0dce627d6f4b7ceda41f36553ee566` reduced **160 -> 159**, but its B.Cu vertical at x=145.8 ran alongside/through U2 output-side PTH apertures, including +12V pad10, producing mask bridges and one short.
- Root cause is now explicit: do not descend beside U2 output pad column on B.Cu.
- Fifth candidate `1b3deb535c66716031a2bf19b6e43e25ecf7b356` escapes left on B.Cu, descends at x=132 outside U2 pad columns, crosses below relay row at y=130, then rises at K11.

## K11 fifth rejected candidate — 2026-10-01

- Candidate `1b3deb535c66716031a2bf19b6e43e25ecf7b356` reduced **160 -> 159** but failed with via-related hole/mask/short violations.
- Key simplification: U2.16 and K11.5 are both through-hole pads, so no layer-change vias are required to use B.Cu.
- Sixth candidate `788b41860645d9cdb9d12693b080ed1e41a214e9` routes net46 entirely on B.Cu: directly from U2.16 left to x=132, below relay row at y=130, then directly into K11.5.

## K11 sixth rejected candidate — 2026-10-01

- Via-free B.Cu candidate `788b41860645d9cdb9d12693b080ed1e41a214e9` again reduced **160 -> 159** but failed: lateral B.Cu escape from U2.16 crosses other plated-through pads in the U2 row.
- Seventh candidate `9cbb0a9ad6a4ae42da3628c2dc245dc33c16bc01` uses a short F.Cu escape to a remote via `(150,98.5)`, then B.Cu outside U2 at x=130 and below relays at y=132, ending directly at K11.5 THT.

## K11 seventh rejected candidate — 2026-10-01

- Candidate `9cbb0a9ad6a4ae42da3628c2dc245dc33c16bc01` reduced **160 -> 159** but produced multiple crossings/shorts.
- Inspection of the official board exposed existing long backbones in the attempted left corridor: net16 on F.Cu around x=128.5 and net17 on B.Cu around x=130.5. The candidate crossed these repeatedly.
- Eighth candidate `14f2a1e058754b0f325a62f690047cc134942b10` avoids the left corridor: short F.Cu escape to the right, via at `(152,99)`, B.Cu descent at x=152, then y=132 below relay row into K11.5.

## K11 eighth rejected candidate — 2026-10-01

- Candidate `14f2a1e058754b0f325a62f690047cc134942b10` reduced **160 -> 159** and substantially reduced geometry conflicts, but still had one track crossing plus two shorts/mask bridges around the transition area.
- Ninth candidate `143b7d8e3745eb45d9df65d70cd7192bf4111c19` moves the F.Cu-to-B.Cu transition beyond K9 to `(162,99.5)` and lowers the B.Cu backbone to y=134 before entering K11.5.

## K11 ninth rejected candidate — 2026-10-01

- Candidate `143b7d8e3745eb45d9df65d70cd7192bf4111c19` reduced **160 -> 159** and narrowed failures to exactly 3 violations.
- DRC evidence: initial F.Cu escape crossed K9 net44 vertical at x=147.5; the long F.Cu segment also crossed K9 pad4 `R9_NO` at `(157.62,99.76)`, causing one short and one solder-mask bridge.
- Tenth candidate `0249f572798492a72d3edee492a3f8f4dcbbec3d` avoids both: short F.Cu escape left to via `(143.5,99)`, then B.Cu x=143.5 to y=134 and across to K11.5.

## K11 validated and promoted / K12 start — 2026-10-01

- K11 candidate 10 `0249f572798492a72d3edee492a3f8f4dcbbec3d`, Route Candidate `36829048742`: **160 -> 159**, zero error-severity DRC violations.
- Promoted exact validated net46 geometry in official board: `22d3f2b4cc33837f3d7836bc771c1eba14583a2e`.
- Sanity gate now approves net46: `0e0a16ba399b72449ab47a3430c59bbf27abba4e`.
- Verified official K12-K16 footprints directly: pad5 endpoints are (211.62,115), (229.62,115), (247.62,115), (265.62,115), (283.62,115).
- K12/net47 candidate `cb24da98b496a8ded0bc87c96a1290f5913806c6` uses a staggered variant of the validated K11 topology: via (143,101.5), B.Cu x=143, lower corridor y=136, K12.5.

## K12 validated and promoted / K13 start — 2026-10-01

- K12 candidates iteratively isolated K11/K10 conflicts; final candidate `d4b72695d6b28b4b8ef0bdb7f43e9477bc797e03`, Route Candidate `36830213836`: **159 -> 158**, zero error-severity DRC violations.
- Promoted exact validated net47 geometry: `dd8bc4059f4ce6603bb334ec920307bdd859ca93`; sanity approval: `60b5597450766b482d425369ccb97190e007f913`.
- K13/net48 candidate `e7a2ac6f155dd92796aaf1ccfccd572ebb9ca45b` starts a staggered mixed-layer corridor; validate before promotion.

## K13 validated and promoted / K14 start — 2026-10-01

- K13 required a controlled multi-layer weave around the dense U2/K9-K12 corridor. Final candidate `e8c343cec4e64c4b1aeb9493270f28f7e2edad7e`, Route Candidate `36830926095`: **158 -> 157**, zero error-severity DRC violations.
- Promoted exact net48 geometry: `ed6538741ede7c8c13bf49c5a07d07e912edf69f`; sanity approval: `7cd69e3a957f27bcba06e4c1a9304fca573e77bf`.
- K14/net49 candidate `6d4f840eca798715aee363e8a9ace09ffbfd599f` started with staggered coordinates; DRC remains authoritative.

## K14 first rejected candidate — 2026-10-01

- Candidate `6d4f840eca798715aee363e8a9ace09ffbfd599f`, Route Candidate `36831044922`, reduced **157 -> 156** but had five track crossings with validated K10/K12/K13 geometry.
- No promotion occurred. Revised candidate `72818bf4bff0f99182f49c627206f51aa03493df` uses a right-side fanout and controlled layer weave; validate it next.

## K14 fanout constraint discovered — 2026-10-01

- Multiple K14/net49 candidates consistently reduce connectivity **157 -> 156**, proving endpoint/net correctness, but none is promotable yet.
- DRC evidence shows the U2.13 escape is boxed by validated routes: K10/K13 on F.Cu, K11/K12 on B.Cu, plus U2.12/U2.11/U2.10 pads and K9 contact/coil pads.
- Best outer-corridor attempt `ff03eec08cb81aab1dc6231e00134e116e4a03dc` left only K11-vs-K14 local conflicts; moving the via left (`4c51bf5fc6e2b27ed5a6c2927e023908c842bb78`) moved the remaining conflicts to the short F.Cu escape against K10/K13.
- Immediate-via attempt `9936fc0a28abaa4dd6564a554f6cee3d8fd327a9` confirmed that simply dropping to B.Cu alongside U2 collides with pads 12/11/10 and K11.
- **No K14 candidate was promoted. Official PCB remains K1-K13, 157 unconnected.**
- Next safe strategy: test a combined temporary reroute that removes/repositions K11/net46 to open an escape lane for K14, then run full KiCad DRC and require no regression before changing the official PCB.

## K14 combined-reroute experiments — 2026-10-01

- Official PCB stayed unchanged at K1-K13 / **157 unconnected** throughout this series.
- Joint K11+K14 candidates `dfd7af45...`, `a8a32429...`, and `fa9e4053...` all preserved connectivity and produced **157 -> 156**; the best result was only two track crossings and no shorts.
- Moving K13 as well (`26902354...`) regressed DRC, so K13 should remain in its validated geometry.
- K14 layer-weave `32fda91e...` and alternate entry `ca57761c...` proved the two-crossing bottleneck is in the U2.13 local fanout, not the lower backbone.
- Next experiment should temporarily repack K11+K12 together while preserving K13, creating a dedicated B.Cu escape lane for K14. No official route should be replaced until the combined candidate has zero error-severity DRC and still reduces unconnected 157 -> 156.

## K14 exact-crossing reduction — 2026-10-01 11:17 CEST

- K11+K12+K14 repack `65b12f29...` regressed to 3 crossings; rejected.
- Right-side K14 escape `83235a25...` entered K9 contact geometry and produced shorts/clearance errors; reject this topology family.
- Inspecting the best K11+K14 artifact proved its two DRC crossings were both on the temporary K11 replacement, while K14 itself was clean.
- Local K11 layer-hop candidate `c2d97e60...` improved the combined route to **one single tracks_crossing**, still **157 -> 156**, with no shorts/clearance errors.
- The remaining crossing is between K11 F.Cu backbone ending at/near `(193.62,146)` and validated K12 F.Cu geometry reported from `(147,136)`; artifact `11150558819` is the cleanest evidence checkpoint.
- Extending the K11 B.Cu section (`5e358898...`, `db215b94...`) trades that one crossing for crossings against K13/K14, so do not use those variants.
- **Official PCB remains unchanged: K1-K13, 157 unconnected.** Best restart base is candidate `c2d97e60287361f5e377c04ce1d9b19ce04a474b`; solve only its final K11/K12 crossing while keeping K14 topology unchanged.

## K14 extended search / local optimum — 2026-10-01 11:36 CEST

Extended autonomous search confirmed the local optimum rather than promoting a marginal route:
- K11 endpoint-from-left `bbc99085...`: 157 -> 156, 1 crossing.
- K11 minimal B.Cu endpoint stub `5d70da72...`: 157 -> 156, 1 crossing.
- Shift endpoint vertical right `f7bf6f79...`: 157 -> 156, 1 crossing.
- Lower F.Cu backbone `2107f249...`: 157 -> 156, 1 crossing.
- Direct B.Cu U2.16 escape `afcc54a1...`: 157 -> 156, 1 crossing.
- Outer x=136 descent `8bb8ef6b...`: produced shorts/mask/clearance; rejected.
- K12+K14 `2ae0c50e...`: 3 crossings; rejected.
- K10+K14 `6e9c4195...`: shorts/mask + 4 crossings; rejected.

Conclusion: moving K10/K12/K13 or changing K11's endpoint/backbone does not beat the K11+K14 candidate `c2d97e60...`, which remains the best known geometry at **one tracks_crossing, zero shorts/clearance, 157 -> 156**. Generator was deliberately restored to that exact candidate in commit `7d5c70de...`. Official PCB remains K1-K13 / 157 unconnected.

Next useful step is to inspect the exact DRC item text/coordinates for artifact `11150558819` and modify only the segment pair named by KiCad. Do not resume broad geometric guessing.

## K14 promoted; K15 started — 2026-10-01 11:55 CEST

- Exact artifact inspection of `11150558819` identified the last K14-blocking violation precisely: K12 F.Cu horizontal at y=136 crossing K11 F.Cu vertical x=193.62.
- Candidate `5a6f8a361b15faae3c396026fbd24d9db01cb418` inserted only a local K11 B.Cu bridge from y=138 to y=134. Route Candidate run `36844515326` **SUCCESS**: 157 -> 156, zero routing DRC errors.
- Promoted K11 replacement + K14/net49 atomically to official PCB in `285ee46f592a7a2ee4197c7c06fb1f488ee47f00`.
- Sanity allow-list updated for net49 in `81a3c3e064615797c101b76999cfe74ef5cfe764`.
- Official KiCad validation after promotion: **156 unconnected**, no critical geometry/electrical categories; fabrication gate fails only because board is intentionally incomplete.

K15/net50:
- Initial B.Cu candidate `81777e02...`: 156 -> 155, exactly one crossing (K15 initial fanout vs K14 vertical).
- Right-side/local-bridge candidate `70fab4b4a9e86a9c205d61f840278a23a06451c5`: 156 -> 155, exactly one crossing, zero shorts/clearance. Artifact `11153127344` identifies it as K15 initial B.Cu segment crossing K12 B.Cu vertical x=147.
- Attempts `d62b78e2...` and `a2d19887...` to bridge near U2 introduce a short; rejected.
- Generator restored to best K15 candidate in `41ef0da662f07cabb78bdffc8f552df953100fd1`.

Next: solve only K15's initial pad escape across K12 x=147, but keep layer changes farther from U2 pads/vias. Official board stays K1-K14 / 156 unconnected until K15 candidate is zero-error.

## K15 extended escape search — 2026-10-01 12:07 CEST

Official remains K1-K14 / 156 unconnected and clean except intentional incompleteness.

K15 experiments from best `70fab4b4...` (156 -> 155, one crossing, zero shorts/clearance):
- `33354716...`: move layer bridge below U2; 2 shorts + 2 mask bridges + 2 crossings. Reject.
- `abafd372...`: separate pad escape/crossing; 3 shorts + 4 mask bridges + hole errors. Reject.
- `75a2ff22...`: long F.Cu escape to x=152; no shorts but 6 crossings. Reject.
- `9c2821ef...`: attempted candidate-only local K12 bridge; generator produced malformed candidate (KiCad failed to load). **No electrical conclusion; this topology still needs a correct test.**
- `3f9d0036...`: B.Cu detour around K12 lower endpoint; 2 shorts + 3 mask bridges. Reject.

Conclusion: do not add vias close to U2 and do not route K15 long-distance on F.Cu. Best known K15 candidate remains `70fab4b4a9e86a9c205d61f840278a23a06451c5`, artifact `11153127344`, with only K15 initial B.Cu escape crossing K12 B.Cu vertical x=147. Generator restored to that exact candidate in `5225dca9ee6584600b84fb2d18bfaad6556e9662`.

Next experiment: correctly construct a candidate that keeps K15 exactly as best-known and replaces only K12's B.Cu x=147 segment with a local F.Cu bridge around the K15 crossing, with vias placed sufficiently far from U2. Validate syntax before DRC.

## K15 promoted; K16 started — 2026-10-01 12:38 CEST

### K15/net50 completion
- Corrected the malformed K12-bridge generator and obtained a valid topology test in `88fe9b7b...`: 156 -> 155, crossings eliminated but two shorts; artifact `11154558418` proved both shorts were K12 bridge vias vs K9 F.Cu vertical x=147.5.
- Repacked K9/net44 away from those vias while keeping the proven K12 bridge and K15 geometry. Candidate `435f8b0439c3839422fc9aa41ebd0fbd59e951f0`, Route Candidate run `36849600656`: **SUCCESS**, 156 -> 155, zero routing DRC errors. Evidence artifact `11154489961`.
- Promoted K9 + K12 repack and K15/net50 atomically to official PCB in `bec89822bcfcb3f2f0540362171a7f785e18f947`; sanity allow-list net50 in `7638b267b49036cdf2a1bbe0fabd7a69d004d471`.
- Official KiCad validation: **155 unconnected**, error-severity DRC violations none, critical geometry/electrical categories none. Fabrication gate fails only because connectivity is intentionally incomplete.

### K16/net51 search
- Initial lower-backbone candidate `60009a8e344c969e03e2cf42ff5496f14314ae5d`: **155 -> 154**, zero shorts/clearance, exactly one crossing. Artifact `11154883351` identifies exact crossing: K16 initial B.Cu escape from U2.11 vs K14 B.Cu vertical x=143.5 (K14 segment 106->142).
- `220fc49f...`: bridge K14 locally onto F.Cu around K16 crossing. Crossing removed, but two shorts; artifact `11155515916` shows both K14 vias collide with K13 F.Cu vertical x=143.0 (segment starting 143,103.5).
- `8fdcf5b2...`: K16 right-side/lower escape; regressed to 2 shorts + 3 crossings. Reject.
- Conclusion: K13 F.Cu x=143 and K14 B.Cu x=143.5 form the two-layer bottleneck. Next solve via coordinated local K13/K14 repack around y~108-114, leaving K16 best geometry unchanged.
- Generator restored to exact best K16 candidate in `993086ce6a043618672e8388f5d7e208f15a1eba`.

## K16 bottleneck search II — 2026-10-01 13:00 CEST

Official PCB unchanged: K1-K15 / 155 unconnected / zero error-severity routing DRC. Best K16 remains `60009a8e...`: 155 -> 154, zero shorts/clearance, one crossing K16 B.Cu escape vs K14 B.Cu x=143.5.

Experiments:
- `566b3c6e...`: move K13 F.Cu vertical to x=140 + K14 F.Cu bridge. 1 short + 3 crossings. Reject.
- `a5122023...`: interleaved K13 B.Cu bridge / K14 F.Cu bridge. 4 shorts + 1 clearance + 1 crossing. Reject.
- `07d8caea...`: short K16 F.Cu escape right. 3 shorts + 1 mask bridge + 2 crossings. Reject.
- `f8a53546...`: K16 F.Cu escape left with remote via at (141,120). No shorts/clearance, but 2 crossings. Interesting but worse than baseline.
- K14 same-layer sidestep family: `1fd13ff9...`, `78bc73c0...`, `9171f3a8...`, `4feb36b5...`, `e8b973a2...`, `52dcbd65...`. All maintain 155 -> 154 with **zero shorts/clearance and exactly one crossing**. Moving K14 left does free the original K16/K14 crossing, but one K14 raccordo then crosses another B.Cu route. This family is geometrically promising but needs exact residual-pair inspection before another coordinate change.

Generator restored to exact best original K16 in `ed4133fbc21dc006f5b7495b5ae489fb1ab66aa2`.
Next: inspect residual crossing from artifact `11155458843` (direct K14 pad escape-left variant) and compare with original artifact `11154883351`; design K14 sidestep endpoints around the actual conflicting B.Cu segment rather than guessing coordinates. Do not disturb proven K16 lower backbone y=158.

## K16 promoted — second relay coil-low bank complete — 2026-10-01 13:22 CEST

- Exact residual sidestep crossing from artifact `11155458843`: K16 B.Cu vertical x=141 (start 141,112, length 46) vs K14 B.Cu horizontal re-entry at y=124 from x=139.5 to x=143.5.
- K14 F.Cu bridge experiment `1b698c15...` proved the only new conflict was K11 F.Cu x=140 vs K14 bridge/via at x=139.5,y=124 (artifact `11156733356`).
- Local K11/net46 F.Cu sidestep x=137 between y=120..130 freed the K14 bridge without disturbing its validated endpoints.
- Final candidate `4a546032d55f9b2b6dfa7e99aa6693296c8b1ee8`, Route Candidate run `36854584445`: **SUCCESS**, 155 -> 154, zero error-severity routing DRC. Evidence artifact `11157941040`.
- Promoted K11 + K14 + K16 atomically to official PCB: `cb164a2313a735384a2130bd7465fa126bc67088`.
- Added net51 to source sanity allow-list: `809c4d85e9f84cf219d28b8c448208f1bbcb94de`.
- Official KiCad Validation run `36854767991`: DRC categories `{'lib_footprint_mismatch': 66, 'unconnected_items': 154}`; **critical geometry/electrical categories none**, error-severity DRC violations none. Gate failure is intentionally only incomplete connectivity; no Gerbers exported.
- Milestone: **all K1-K16 relay coil-low outputs are now routed and KiCad-validated**.

Next phase is not blind relay-contact routing. Inventory the 154 remaining connections and route low-risk logic/control nets first; power/high-current and relay-contact nets remain a separately reviewed phase. Keep Gerber gate closed until zero real DRC errors + zero unconnected.

## Relay-input fanout reconnaissance — 2026-10-01 13:36 CEST

Official board remains the validated K1-K16 milestone: 154 unconnected, zero critical routing DRC. No input candidate promoted.

Residual low-risk target block identified: nets 20..35 = D25_RELAY1..D40_RELAY16, MCU1 -> U1/U2 inputs. U1 inputs are x=135,y=62..79.78; U2 inputs x=135,y=92..109.78. MCU1 absolute relay pads alternate x=121.98/124.52 from y=46.28 through 66.60.

Probes:
- D25 F.Cu direct `b8adaee1...`: 154->153 but 1 short + 1 crossing + 1 solder-mask bridge.
- D25 same geometry B.Cu `3945740e...`: same violation pattern, proving corridor geometry rather than layer is the problem.
- D25 external-left B.Cu `7bb85a63...`: worse (clearance/short/mask/crossings); left edge around MCU is occupied.
- D40 lower direct `96b9ecd3...`: 154->153 but hole-clearance + short + mask + crossing near MCU corridor.

Conclusion: D25-D40 should be designed as coordinated 8-wire fanout banks, not independent point routes. Next action: map existing copper/through-hole obstacles around MCU x=118..136,y=44..112 and choose parallel fanout channels, then candidate a small 2-4 net bundle before promoting. Generator restored to D25 baseline in `8c099ae9a83cd995c3144e2a6d322096148466c2`; this is only a reproducible probe, not a promotion candidate.

## Relay-input fanout: D25/D26 promoted — 2026-10-01 13:55 CEST

- Copper map exposed two existing walls between MCU and ULN: net16/D22_START on F.Cu around x=128.5 and net17/D23_NEXT on B.Cu around x=130.5. Correct fanout topology is B.Cu from MCU across the F.Cu wall, via in the narrow inter-wall channel, then F.Cu across the B.Cu wall.
- D25/net20: first cross-layer candidate `5029ffc8...` had only C2 GND collision (F.Cu x=132.5). Bypass C2 right produced clean candidate `c38f647f09050b5915d6ec04d9d82ce5786b3b6f`, run `36857389224`: 154->153, zero routing DRC. Promoted official `927f3d8c9e16484040cb668d39c13c5091dda538`, sanity `f3f9c3ed69bae9054c121c1bc906fa3a7ca9ad80`.
- D26/net21: initial probe crossed D27 pad and D25. Final route uses B.Cu lane between MCU pad rows, via (129.5,50.09), F.Cu x=131.5 left of C2/D25, then horizontal into U1.2. Clean candidate `02ed5d909c3eda6c1582b5165e66c792c7ad92cd`, run `36858026986`: 153->152, zero routing DRC. Promoted official `d3f6b0a3d65586243c27053727199f439ad5e85a`, sanity `0ad9e773077e304f013aa442f453ca1791a9fdc0`.
- Official board is now **152 unconnected** with D25+D26 added to the previously clean K1-K16 milestone.
- D27/net22 candidate `e154a246...` reduces 152->151 with no shorts/clearance, but 4 crossings. Exact pairs from artifact `11160176400`: (1) D27 F start at 129.5,54.5 vs D22_START F track at 130.5,54; (2) D27 B pad escape vs D26 B horizontal y=50.09; (3) D27 F start vs D26 F vertical x=131.5; (4) D27 F vertical x=133 vs D26 F horizontal y=64.54. Next: redesign D27 as a comb lane around those four known segments; do not disturb validated D25/D26 unless coordinated candidate proves clean.

## D27/D28 fanout search — 2026-10-01 14:04 CEST

Official D25/D26 board independently revalidated by PCB KiCad Validation run `36858485914`: categories `{'lib_footprint_mismatch': 66, 'unconnected_items': 152}`; critical geometry/electrical categories none. Gate failure only incomplete connectivity; Gerbers skipped.

D27 experiments after checkpoint:
- right-side fanout `63ffe450...`: worse (1 short, 2 mask bridges, 3 crossings), reject.
- coordinated D26 repack + D27 `d67059cf...`: 1 short + 1 clearance + 3 crossings, reject; preserve clean official D26.
- best remains `e154a246...`: 152->151, **zero shorts/clearance**, four crossings, all previously identified.
D28 even-lane probe `d56c5145...`: 152->151 but 4 shorts + 2 mask + 2 crossings, confirming the narrow x=128.5..130.5 inter-wall channel cannot simply host additional independent vias/traces after D25/D26.

Conclusion: next progress requires a coordinated fanout-bus repack, not more isolated routes. Preserve official D25/D26 as baseline; model D27-D32 together, likely with staggered layer-change stations at different Y and/or one atomic repack of D25-D32. Generator restored to best D27 in `a4e29afc4a56b875a72812e5a8a0b55bf0510c06` for reproducible baseline.

## Manufacturing deliverable target clarified — 2026-10-01

Final project gate is not merely a routed PCB. Required handoff is an assembly-service-ready manufacturing package containing at minimum:
- Gerber fabrication layers plus Excellon drill files, packaged for upload;
- BOM (bill of materials) with reference designators, quantities, values/MPNs and assembly-relevant sourcing fields where known;
- CPL / component placement / centroid list with reference, X/Y, side and rotation in a consistent origin/convention;
- validation that BOM/CPL references match the PCB and that generated fabrication files correspond to the same committed board revision.

Keep current Gerber export gate closed until zero real DRC errors and zero unconnected items. Once routing/fabrication gate passes, generate and validate Gerber + BOM + CPL as the final deliverable bundle rather than stopping at KiCad sources.

## Manufacturing-target follow-up / START repack probe — 2026-10-01

- Final assembly-service requirement (Gerber+drill, BOM, CPL) recorded in project checkpoint; these artifacts must all be generated from and cross-checked against the same final committed PCB revision.
- Investigated freeing MCU->ULN fanout by moving D22_START/net16 away from x=128.5. Candidate `2e7d983d...` moved the long F.Cu backbone to x=108, but DRC produced 7 shorts, 6 mask bridges and 3 crossings. Rejected; official PCB unchanged.
- This confirms the central/left region is obstacle-dense and a wholesale control-net move is not justified without a real routing search. Generator restored to best D27 candidate at `9dfb714f24ab70e5392f0cbebac2d4b77721db25`.
- Official production source remains 152 unconnected with no critical geometry/electrical DRC (last verified run `36858485914`).

## D27 promoted / D28 structural search — 2026-10-01

- D27/net22 solved with a two-via topology that avoids the future Mega relay-pad column. Near-final `b4b4fa61...` reduced errors to only C2 +12V collision; shifting the B.Cu vertical from x=127 to x=126 cleared it.
- Final D27 candidate `fc0e3274e039a829cef709cb772e92feb6e241b6`, Route Candidate run `36861858225`: **SUCCESS**, 152->151, zero routing DRC errors.
- Promoted D27 official: `f2e4c50a032b9b3cbcc343b89e67a3e54d10981f`; sanity allow-list through net22: `0a6bfe6f704635acf52494c0b4b361d0d40b8471`.
- Official board is now **151 unconnected**.

D28/net23 search:
- inter-pad two-via `e598c821...`: 151->150 but 3 shorts + 1 mask + 2 crossings; exact conflicts include C2 and D27 lanes.
- below-relay-header `20a17bb0...`: 151->150, **zero crossings**, only 1 short + 2 mask. Exact remaining obstacle is not a used relay net: Mega physical header continues with no-net pads D42 at (121.98,69.14) and D43 at (124.52,69.14). Therefore routing below D40 at y≈69 is still inside the physical header.
- Next D28 direction: pass below the entire Mega digital header (not merely D25-D40), then cross toward U1 on the appropriate layer, or use a similarly separated outer corridor. Preserve clean D25-D27.

Manufacturing end target remains assembly-ready Gerber+drill ZIP + BOM + CPL, generated only after zero real DRC + zero unconnected and cross-checked to the same revision.

## D28 promoted / D29 start — 2026-10-01 15:10 CEST

- Concurrent branch work had already completed D27: official f2e4c50a..., sanity 0a6bfe6f..., 151 unconnected.
- D28/net23 solved after mapping the full Mega header. Key obstacle stack: D24_TEST B.Cu around x=117, D22_START F.Cu x=128.5, D23_NEXT B.Cu x=130.5, plus analog header row at y=89.46. Successful topology uses a layer-lock: F.Cu from D28 through midpoint x=110.55 between A11/A12, cross TEST on F at y=92, via (127,92), cross START on B, via (129.5,92), cross NEXT on F, then return above U2 and enter U1.4.
- Final D28 candidate 61fcb1d6ce842ba8100e617b474577927426e17e, Route Candidate run 36865837527: SUCCESS, 151->150, zero routing DRC.
- Promoted official 095233fc564d720196f9259d7ef4c0053fadeade; sanity dc2b5e9288273f8bed750f5c5de49f94036aa08c.
- Independent official validation observed on run 36866316897: categories lib_footprint_mismatch=66, unconnected_items=150; critical geometry/electrical none.

D29/net24 first staggered probe c4d7cec6... connects 150->149 but is rejected: 3 shorts + 3 mask bridges + 2 crossings. Exact causes: initial F.Cu escape touches D30 pad; long leftward y54 route crosses D28 vertical; return at y91 touches U2.1 (D33); right-side ascent crosses D28 x140. Next D29 design should NOT clone D28 leftward escape. Prefer a right-of-header/vertical corridor or a coordinated D29/D30 escape that leaves both pads without crossing each other, while reusing the validated wall-crossing concept.

Official board remains **150 unconnected / zero critical geometry/electrical DRC**. Manufacturing gate unchanged: zero real DRC + zero unconnected before Gerber; final bundle Gerber+Excellon ZIP + BOM + CPL.

## D29 promoted / D30 start — 2026-10-01 16:08 CEST

- D29/net24 required several rejected families. Outer-right route proved its remote section clean but exposed the local pad escape blockage from D27/D26/D25. Coordinated D27 repack reduced errors but did not clear D26/D25 crossings and was rejected.
- Successful D29 topology uses the physical inter-pad corridor between D28/D30, then crosses TEST/START/NEXT with deliberate layer locks. Final key corridor is y=80.57, midpoint between Mega D50/D51 and D52/D53 rows: F.Cu crosses TEST(B), via x127, B.Cu crosses START(F), via x129.5, F.Cu crosses NEXT(B), then x132 into U1.5.
- Final D29 candidate `fdeb1ecde2a6d61a3bfce07df42df195cdded63c`, Route Candidate run `36873633369`: **SUCCESS**, 150->149, zero routing DRC errors.
- Promoted official D29 `b6ba98a856ac02f48155f664b1b0eaf3362f9bc5`; sanity allow-list net24 `ff67854db31d4626c20260fa8f586047bdf681e0`.
- Official board is now **149 unconnected** with D25-D29 routed.
- D30/net25 candidate `cd71514a7a079843dc92f24f6da86afe8916eea7` uses complementary alternating-layer path at y=78.03 and is awaiting Route Candidate run `36874130419`. Do not infer success until DRC completes.

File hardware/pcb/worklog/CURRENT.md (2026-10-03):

# PCB work checkpoint

This file is the short restart point for long autonomous PCB sessions.

## Current baseline
- Branch: `dev`.
- Official board: `hardware/pcb/kicad/PSN-Presepe-Mega.kicad_pcb`.
- Official board contains K1-K12 coil-low routing; K12 added six track segments plus one via after K11 baseline.
- Routing is being promoted only after a temporary candidate passes real KiCad DRC.
- K1-K13 relay coil-low routes are promoted and sanity-approved. K14 is in candidate validation.
- Gerber fabrication gate remains blocked until DRC has no real errors and connectivity is complete.

## Restart procedure
1. Fetch HEAD versions of this file, `make_route_candidate.py`, `pcb_sanity.py`, PCB and workflow.
2. Inspect the newest `pcb-kicad.yml` Actions run and its logs/artifacts.
3. Never assume a candidate was promoted merely from its script: confirm the official PCB segment count and sanity allow-list.
4. If candidate DRC is clean and reduces connectivity, promote only that verified route in a dedicated commit.
5. Update this checkpoint after each meaningful routing milestone.
6. Keep experimental generated boards out of the official PCB; CI build paths are disposable.

## Commit discipline
Use small commits with one purpose:
- `WIP candidate: <net>` for experiment infrastructure or route candidate;
- `Promote KiCad-validated <net> route` only after clean candidate DRC;
- `Checkpoint PCB routing state` for this restart log;
- documentation/tooling changes separately from electrical PCB changes.

## Safety invariants
- Do not blind-route relay contact/mains-capable nets.
- No unreviewed copper zones.
- Preserve perimeter terminal placement and MOSFET heatsink spacing.
- Keep the explicit fabrication gate; never generate production Gerbers from an incomplete board.
- Fetch HEAD immediately before every PCB/tool/workflow update to avoid overwriting concurrent work.

## Next action
Official board promotion completed on `dev` at commit `cf84acada8c95eb92ad755395199ef8dcfbbcb3d`: the second validated Freerouting delta reduced connectivity from **122 to 120 unconnected pads (-2)** with no new critical DRC categories.

The two newly solved logic connections are:
- `D36_RELAY12`: MCU1 D36 -> U2 pad 4.
- `CIELO_G_NEG`: Q2 pad 2 -> J_CIELO pad 3.

Exactly **3 logic connections remain**:
- `TRAM_R_NEG`
- `TRAM_G_NEG`
- `ALBA_B_NEG`

The remaining 117 non-logic unconnected reports are still the planned **48 relay-contact + 69 power** routing workload. Close these 3 logic stragglers with targeted candidates and real KiCad DRC before relay-contact routing, then power buses/zones.

Validated artifact for the 122->120 delta: run `36898305562`, artifact `11180751893`; promotion run `36900932623` completed successfully. Keep autoroute artifact-only and protected power/contact nets stripped.

Final fabrication gate remains zero real DRC + zero unconnected -> same-revision Gerber+Excellon ZIP + BOM CSV + CPL/centroid CSV.

Progress checkpoint after 122->120 promotion: ~66% routing / ~76% overall PCB.

## ALBA_B targeted routing investigation (2026-10-01)
Official board remains at **118 unconnected**; no experimental candidate has been promoted.

Target net: `ALBA_B_NEG` (net 61), Q9.2 `(112.54,165)` -> J_ALBA.4 `(171.24,184)`.

A dedicated KiCad 9 container workflow now batches candidate routes and runs real DRC without repeated APT installation:
`.github/workflows/pcb-targeted-alba-b.yml`.

Every tested route electrically closes ALBA_B and reaches **117 unconnected**, but all current geometries still create critical DRC collisions, so promotion is correctly blocked. Main geometric barriers observed around the Q9 escape/destination corridor include `D22_START`, `D24_TEST`, `CIELO_R_NEG`, `CIELO_G_NEG`, `CIELO_B_NEG`, `TRAM_B_NEG`, `ALBA_R_NEG`, and `ALBA_G_NEG`.

Best diagnostic families so far reduced the error classes to `tracks_crossing` / `shorting_items` (some variants also introduce clearance/hole/solder-mask issues). Direct, lower-edge, upper, mixed-layer, fine sweep, and dogleg topologies have been tested. Do not promote any of them.

Next best practice: stop hand-picking polylines and make the targeted router obstacle-aware from the actual PCB copper/pads/vias, searching a clearance-inflated grid independently on F.Cu/B.Cu with via transitions. Require 117 unconnected and no new critical DRC before promotion.

## ALBA_B closed on official board (2026-10-01)
Milestone reached on `dev`: official board is now **117 unconnected** with **no critical geometry/electrical DRC categories** and **no error-severity DRC violations**.

Final ALBA_B route is net 61. The only post-promotion clearance issue was between the ALBA_B via at `(127.5,172.75)` and `ALBA_G_NEG`: RGB_LOAD requires 0.300 mm clearance. Keeping the validated route geometry and changing that via from 0.8/0.4 mm to **0.6/0.3 mm** removes the violation. Official electrical board commit: `8dba41f28c25e780997ea7a1cd376aa72ea8b58f`.

Official KiCad validation reports:
- 117 unconnected items
- critical geometry/electrical categories: none
- error-severity DRC violations: none
- remaining non-critical/incomplete-board categories include planned unconnected items, footprint-library mismatch, existing hole-to-hole notices and a dangling-via notice.

The fabrication workflow remains intentionally red until **zero unconnected**; do not weaken that gate.

Remaining connectivity workload is now exactly the planned non-logic work:
- **48 relay-contact connections**
- **69 power connections**
- **0 logic connections**

Next stage: route relay contacts parametrically/in reviewed batches with mains-capable clearance/isolation rules; do not use blind generic autorouting. Power buses/zones remain last.

## Relay-contact milestone (2026-10-02)
Official board on `dev` has advanced from the 117-unconnected logic-complete baseline to a promoted **75-unconnected relay checkpoint** (commits `2acb44b...` / `89188ab...`). This means 42 connectivity items have been removed since the 117 baseline. Current targeted work is the final relay-contact subset; power routing remains last. A corrected obstacle router now applies footprint rotation consistently to real pad geometry. Revalidate the official 75 baseline with the normal KiCad workflow before any further promotion; never replace it with an experimental candidate that has shorts/clearance errors.

## Validated relay batch checkpoint (2026-10-02)
Promoted exact artifact from relay run `36943389801` at commit `ce40b5714b637355b450c43f20231f18ec328107`: **76 unconnected** in candidate DRC, with no clearance/short/track-dangling error categories. This preserves the previously verified 93-unconnected clean baseline and adds 17 conservatively routed relay-contact nets. Expected remaining connectivity: **7 relay contacts + 69 power = 76**. Run normal official-board KiCad validation immediately after this checkpoint and treat that result as authoritative.
\n- Relay cumulative A* candidate promoted by CI validation: 75 unconnected; no new electrical/geometry DRC classes.\n\n- Relay cumulative A* candidate promoted by CI validation: 74 unconnected; no new electrical/geometry DRC classes.\n

## 2026-10-02 relay milestone
- Official board reduced from 117 to 75 unconnected by cumulative DRC-clean relay-contact routing.
- R11_NC (net 102) subsequently routed and promoted: official baseline now **74 unconnected**.
- Promotion run: 36969265054; candidate reported unconnected=74 and no new critical DRC categories.
- Remaining stubborn relay contacts: R14_COM, R15_NC, R16_COM, R16_NO, R16_NC.
- Active strategy: dual-layer A* with high via cost plus multiresolution 0.5/0.25/0.125 mm search; do not reduce relay-contact search clearance below 1.50 mm in current experiments.
- pcb_sanity whitelist updated for promoted net 102.

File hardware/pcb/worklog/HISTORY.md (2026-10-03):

# PCB autonomous work history

Concise durable milestones for restarting long routing sessions.

## 2026-10-01 — checkpoint system introduced
- Stable branch: `dev`.
- Restart summary: `worklog/CURRENT.md`.
- Official PCB SHA at checkpoint: `0ef369ad11c01e8dfbe0f1b5c71bfe0acbc25dce`.
- Official routed copper: 77 segments across 18 nets.
- Real KiCad 9.0.9 DRC: 0 error-severity violations, 167 unconnected items.
- Baseline before routing work was 194 unconnected items; verified progress = 27 fewer.
- Routed nets present: D22_START, D23_NEXT, D24_TEST, D20_SDA, D21_SCL, A0_POT, GATE_Q1..Q9, RELAY1_COIL_LOW, RELAY2_COIL_LOW, RELAY3_COIL_LOW.
- K1/K2/K3 coil routes were promoted only after candidate validation.
- Added isolated `PCB Routing Lab` workflow on `dev` so candidate experiments no longer depend on the stable fabrication workflow.
- Current experiment: RELAY4_COIL_LOW / K4.

## 2026-10-01 — K4 promoted
- Routing Lab run 36822701116: baseline 167 unconnected, K4 candidate 166.
- Candidate error-severity DRC: 0 violations.
- Promoted RELAY4_COIL_LOW as 4 F.Cu segments in commit `c8a58e53350999d83ced2cef67cfb762959357a3`.
- Official board now has 81 routed segments; next relay-coil target is K5.

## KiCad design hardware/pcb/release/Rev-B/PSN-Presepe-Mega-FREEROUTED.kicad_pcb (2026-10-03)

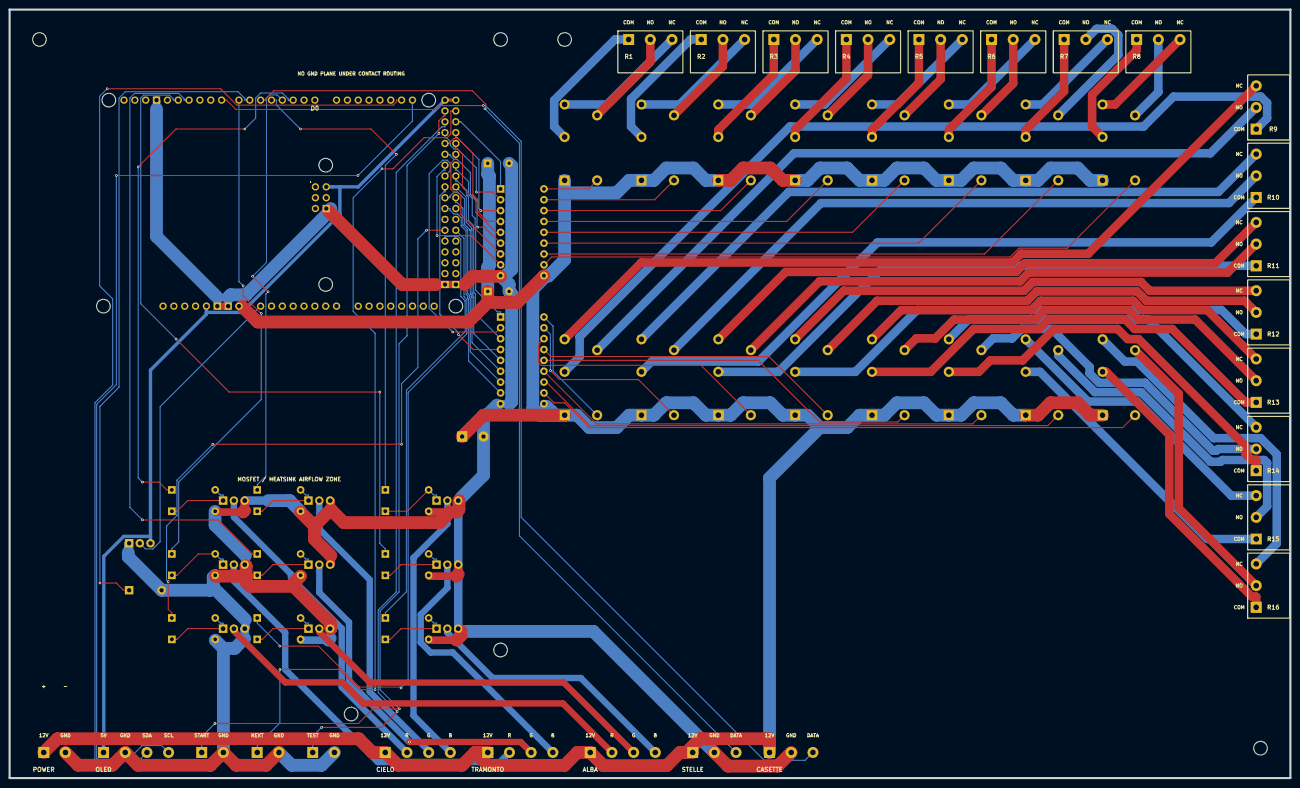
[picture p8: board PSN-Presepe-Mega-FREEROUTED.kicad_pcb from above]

Board: 2 copper layers, 300.0 x 180.0 mm, 83 parts (0 on the bottom side), 119 nets.

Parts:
BZ1: PASSIVE_BUZZER_D6; Buzzer_12x9.5RM7.6
C1: 470uF_25V_RELAY_BULK; C_Radial_D10.0mm_H12.5mm_P5.00mm
C2: 100nF_ULN1; C_Disc_D5.0mm_W2.5mm_P5.00mm
C3: 100nF_ULN2; C_Disc_D5.0mm_W2.5mm_P5.00mm
H1: M3_NPTH; MountingHole_1
H2: M3_NPTH; MountingHole_2
H3: M3_NPTH; MountingHole_3
H4: M3_NPTH; MountingHole_4
H5: M3_NPTH; MountingHole_5
H6: M3_NPTH; MountingHole_6
J1: 12V_IN
JR1, JR2, JR3, JR4, JR5, JR6, JR7, JR8, JR9, JR10, JR11, JR12, JR13, JR14, JR15, JR16: COM_NO_NC; TerminalBlock_Phoenix_MKDS-1.5-3-5.08
J_ALBA: ALBA_12V_R_G_B
J_CASETTE: CASETTE_12V_GND_DATA
J_CIELO: CIELO_12V_R_G_B
J_NEXT: NEXT_GND
J_OLED: OLED_5V_GND_SDA_SCL
J_START: START_GND
J_STELLE: STELLE_12V_GND_DATA
J_TEST: TEST_GND
J_TRAMONTO: TRAMONTO_12V_R_G_B
K1, K2, K3, K4, K5, K6, K7, K8, K9, K10, K11, K12, K13, K14, K15, K16: G5Q-1_DC12; Relay_Omron_G5Q-1_SPDT
MCU1: Arduino_Mega2560_R3_Shield
Q1: IRLZ44N_CIELO_R; TO-220-3_Vertical
Q2: IRLZ44N_CIELO_G; TO-220-3_Vertical
Q3: IRLZ44N_CIELO_B; TO-220-3_Vertical
Q4: IRLZ44N_TRAM_R; TO-220-3_Vertical
Q5: IRLZ44N_TRAM_G; TO-220-3_Vertical
Q6: IRLZ44N_TRAM_B; TO-220-3_Vertical
Q7: IRLZ44N_ALBA_R; TO-220-3_Vertical
Q8: IRLZ44N_ALBA_G; TO-220-3_Vertical
Q9: IRLZ44N_ALBA_B; TO-220-3_Vertical
RG1, RG2, RG3, RG4, RG5, RG6, RG7, RG8, RG9: 100R_GATE; R_Axial_DIN0207_L6.3mm_D2.5mm_P10.16mm_Horizontal
RPD1, RPD2, RPD3, RPD4, RPD5, RPD6, RPD7, RPD8, RPD9: 100K_PULLDOWN; R_Axial_DIN0207_L6.3mm_D2.5mm_P10.16mm_Horizontal
RV1: B10K; Potentiometer_Alps_RK09K_Single_Horizontal
U1, U2: ULN2803C; ULN2803C_DIP18

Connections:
+5V_MEGA: J_OLED.1, MCU1.5V1, MCU1.5V2, MCU1.5V3, MCU1.5V4, RV1.3
+12V: C1.1, C2.1, C3.1, J1.1, J_ALBA.1, J_CASETTE.1, J_CIELO.1, J_STELLE.1, J_TRAMONTO.1, K1.1, K2.1, K3.1, K4.1, K5.1, K6.1, K7.1, K8.1, K9.1, K10.1, K11.1, K12.1, K13.1, K14.1, K15.1, K16.1, MCU1.VIN, U1.10, U2.10
A0_POT: MCU1.A0, RV1.2
ALBA_B_NEG: J_ALBA.4, Q9.2
ALBA_G_NEG: J_ALBA.3, Q8.2
ALBA_R_NEG: J_ALBA.2, Q7.2
CIELO_B_NEG: J_CIELO.4, Q3.2
CIELO_G_NEG: J_CIELO.3, Q2.2
CIELO_R_NEG: J_CIELO.2, Q1.2
D2_CIELO_R: MCU1.D2, RG1.1
D3_CIELO_G: MCU1.D3, RG2.1
D4_CIELO_B: MCU1.D4, RG3.1
D5_STELLE_DATA: J_STELLE.3, MCU1.D5
D6_BUZZER: BZ1.1, MCU1.D6
D7_TRAM_R: MCU1.D7, RG4.1
D8_CASETTE_DATA: J_CASETTE.3, MCU1.D8
D11_TRAM_G: MCU1.D11, RG5.1
D12_TRAM_B: MCU1.D12, RG6.1
D20_SDA: J_OLED.3, MCU1.D20
D21_SCL: J_OLED.4, MCU1.D21
D22_START: J_START.1, MCU1.D22
D23_NEXT: J_NEXT.1, MCU1.D23
D24_TEST: J_TEST.1, MCU1.D24
D25_RELAY1: MCU1.D25, U1.1
D26_RELAY2: MCU1.D26, U1.2
D27_RELAY3: MCU1.D27, U1.3
D28_RELAY4: MCU1.D28, U1.4
D29_RELAY5: MCU1.D29, U1.5
D30_RELAY6: MCU1.D30, U1.6
D31_RELAY7: MCU1.D31, U1.7
D32_RELAY8: MCU1.D32, U1.8
D33_RELAY9: MCU1.D33, U2.1
D34_RELAY10: MCU1.D34, U2.2
D35_RELAY11: MCU1.D35, U2.3
D36_RELAY12: MCU1.D36, U2.4
D37_RELAY13: MCU1.D37, U2.5
D38_RELAY14: MCU1.D38, U2.6
D39_RELAY15: MCU1.D39, U2.7
D40_RELAY16: MCU1.D40, U2.8
D44_ALBA_R: MCU1.D44, RG7.1
D45_ALBA_G: MCU1.D45, RG8.1
D46_ALBA_B: MCU1.D46, RG9.1
GATE_Q1: Q1.1, RG1.2, RPD1.1
GATE_Q2: Q2.1, RG2.2, RPD2.1
GATE_Q3: Q3.1, RG3.2, RPD3.1
GATE_Q4: Q4.1, RG4.2, RPD4.1
GATE_Q5: Q5.1, RG5.2, RPD5.1
GATE_Q6: Q6.1, RG6.2, RPD6.1
GATE_Q7: Q7.1, RG7.2, RPD7.1
GATE_Q8: Q8.1, RG8.2, RPD8.1
GATE_Q9: Q9.1, RG9.2, RPD9.1
GND: BZ1.2, C1.2, C2.2, C3.2, J1.2, J_CASETTE.2, J_NEXT.2, J_OLED.2, J_START.2, J_STELLE.2, J_TEST.2, MCU1.GND1, MCU1.GND2, MCU1.GND3, MCU1.GND4, MCU1.GND5, MCU1.GND6, Q1.3, Q2.3, Q3.3, Q4.3, Q5.3, Q6.3, Q7.3, Q8.3, Q9.3, RPD1.2, RPD2.2, RPD3.2, RPD4.2, RPD5.2, RPD6.2, RPD7.2, RPD8.2, RPD9.2, RV1.1, U1.9, U2.9
R1_COM: JR1.1, K1.2
R1_NC: JR1.3, K1.3
R1_NO: JR1.2, K1.4
R2_COM: JR2.1, K2.2
R2_NC: JR2.3, K2.3
R2_NO: JR2.2, K2.4
R3_COM: JR3.1, K3.2
R3_NC: JR3.3, K3.3
R3_NO: JR3.2, K3.4
R4_COM: JR4.1, K4.2
R4_NC: JR4.3, K4.3
R4_NO: JR4.2, K4.4
R5_COM: JR5.1, K5.2
R5_NC: JR5.3, K5.3
R5_NO: JR5.2, K5.4
R6_COM: JR6.1, K6.2
R6_NC: JR6.3, K6.3
R6_NO: JR6.2, K6.4
R7_COM: JR7.1, K7.2
R7_NC: JR7.3, K7.3
R7_NO: JR7.2, K7.4
R8_COM: JR8.1, K8.2
R8_NC: JR8.3, K8.3
R8_NO: JR8.2, K8.4
R9_COM: JR9.1, K9.2
R9_NC: JR9.3, K9.3
R9_NO: JR9.2, K9.4
R10_COM: JR10.1, K10.2
R10_NC: JR10.3, K10.3
R10_NO: JR10.2, K10.4
R11_COM: JR11.1, K11.2
R11_NC: JR11.3, K11.3
R11_NO: JR11.2, K11.4
R12_COM: JR12.1, K12.2
R12_NC: JR12.3, K12.3
R12_NO: JR12.2, K12.4
R13_COM: JR13.1, K13.2
R13_NC: JR13.3, K13.3
R13_NO: JR13.2, K13.4
R14_COM: JR14.1, K14.2
R14_NC: JR14.3, K14.3
R14_NO: JR14.2, K14.4
R15_COM: JR15.1, K15.2
R15_NC: JR15.3, K15.3
R15_NO: JR15.2, K15.4
R16_COM: JR16.1, K16.2
R16_NC: JR16.3, K16.3
R16_NO: JR16.2, K16.4
RELAY1_COIL_LOW: K1.5, U1.18
RELAY2_COIL_LOW: K2.5, U1.17
RELAY3_COIL_LOW: K3.5, U1.16
RELAY4_COIL_LOW: K4.5, U1.15
RELAY5_COIL_LOW: K5.5, U1.14
RELAY6_COIL_LOW: K6.5, U1.13
RELAY7_COIL_LOW: K7.5, U1.12
RELAY8_COIL_LOW: K8.5, U1.11
RELAY9_COIL_LOW: K9.5, U2.18
RELAY10_COIL_LOW: K10.5, U2.17
RELAY11_COIL_LOW: K11.5, U2.16
RELAY12_COIL_LOW: K12.5, U2.15
RELAY13_COIL_LOW: K13.5, U2.14
RELAY14_COIL_LOW: K14.5, U2.13
RELAY15_COIL_LOW: K15.5, U2.12
RELAY16_COIL_LOW: K16.5, U2.11
TRAM_B_NEG: J_TRAMONTO.4, Q6.2
TRAM_G_NEG: J_TRAMONTO.3, Q5.2
TRAM_R_NEG: J_TRAMONTO.2, Q4.2

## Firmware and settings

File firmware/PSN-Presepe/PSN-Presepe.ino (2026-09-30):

/*
  PresepeController - FASE 1 v2
  Arduino Mega 2560

  USCITE
    D2 = Cielo RGB Rosso
    D3 = Cielo RGB Verde
    D4 = Cielo RGB Blu
    D5 = DATA stelle WS2811 (50 pixel, 12 V)
    D8 = DATA WS2811 CASETTE (riservato, non ancora pilotato)
    D6 = Buzzer piezo passivo opzionale
    D7/D11/D12 = RGB laterale SINISTRA / TRAMONTO (R/G/B)
    D44/D45/D46 = RGB laterale DESTRA / ALBA (R/G/B)

  COMANDI DEFINITIVI
    D22 = START/STOP (pulsante NO verso GND)
    D23 = AVANTI     (pulsante NO verso GND)
    D24 = TEST       (pulsante NO verso GND)
    A0  = Potenziometro lineare B10K

  POTENZIOMETRO
    estremo 1 -> +5V
    cursore  -> A0
    estremo 3 -> GND

  CICLO
    GIORNO -> TRAMONTO -> CREPUSCOLO -> NOTTE -> ALBA -> GIORNO

  Potenziometro:
    tre velocita' discrete: ciclo completo da 1, 3 o 5 minuti.

  Serial Monitor: 115200 baud

  STELLE WS2811:
    +12V -> alimentatore 12 V protetto
    GND  -> 0 V alimentatore E GND Arduino (massa comune)
    DATA -> D5 tramite resistenza 330-470 ohm
    MOSFET #1 canale 4 libero

  NOTA MOSFET:
  Quando avremo verificato il B0GXDL8N7D reale, se gli ingressi
  risultassero active-low basta impostare PWM_INVERTED = true.
*/

#include <Arduino.h>
#include <Adafruit_NeoPixel.h>
#include <Wire.h>
#include <Adafruit_GFX.h>
#include <Adafruit_SSD1306.h>

// ============================================================
// CONFIGURAZIONE PIN
// ============================================================

const uint8_t PIN_CIELO_R = 2;
const uint8_t PIN_CIELO_G = 3;
const uint8_t PIN_CIELO_B = 4;
const uint8_t PIN_STELLE_DATA = 5;
const uint8_t PIN_CASETTE_DATA = 8; // seconda catena WS2811 CASETTE
const uint8_t PIN_BUZZER = 6; // piezo passivo opzionale: se assente il firmware funziona normalmente

// Strisce RGB laterali da 1 m, dedicate agli effetti direzionali.
// Sinistra = tramonto; destra = alba.
const uint8_t PIN_TRAMONTO_R = 7;
const uint8_t PIN_TRAMONTO_G = 11;
const uint8_t PIN_TRAMONTO_B = 12;
const uint8_t PIN_ALBA_R = 44;
const uint8_t PIN_ALBA_G = 45;
const uint8_t PIN_ALBA_B = 46;
const uint16_t NUM_STELLE = 50;
const uint16_t NUM_CASETTE = 50; // numero massimo predisposto; ridurre quando sara\' noto il numero reale
const uint8_t STELLE_ATTIVE = 20;
const uint8_t STELLE_TREMOLANTI = STELLE_ATTIVE; // tutte le 20 stelle attive scintillano
Adafruit_NeoPixel stelle(NUM_STELLE, PIN_STELLE_DATA, NEO_GRB + NEO_KHZ800);
Adafruit_NeoPixel casette(NUM_CASETTE, PIN_CASETTE_DATA, NEO_GRB + NEO_KHZ800);

const uint8_t PIN_START = 22;
const uint8_t PIN_NEXT  = 23;
const uint8_t PIN_TEST  = 24;
const uint8_t PIN_POT   = A0;


// -----------------------------------------------------------------------------
// RELÈ: 4 moduli x 4 canali = 16 uscite ON/OFF predisposte.
// D25-D40 sono riservati al cablaggio IN1..IN4 dei quattro moduli.
// La logica scenografica usa una tabella di schedulazione per fase/percentuale.
// -----------------------------------------------------------------------------
const uint8_t PIN_RELE[16] = {
  25, 26, 27, 28,
  29, 30, 31, 32,
  33, 34, 35, 36,
  37, 38, 39, 40
};

const bool PWM_INVERTED = false;
const bool RELE_ACTIVE_LOW = false; // Wokwi: HIGH=ON; verificare i moduli reali prima del collegamento
const bool BUZZER_ENABLED = true;   // false = silenzia tutto; il buzzer resta sempre opzionale

// OLED ELEGOO EL-SM-008, 128x64, I2C 0x3C.
// Il display e' opzionale: se assente il presepe continua normalmente.
const uint8_t OLED_ADDR = 0x3C;
const uint8_t OLED_W = 128;
const uint8_t OLED_H = 64;
Adafruit_SSD1306 display(OLED_W, OLED_H, &Wire, -1);
bool oledPresente = false;
unsigned long oledPopupFino = 0;
enum OledPopup { OLED_NESSUNO, OLED_PAUSA, OLED_RIPRESA, OLED_AVANTI, OLED_TEST, OLED_VELOCITA };
OledPopup oledPopup = OLED_NESSUNO;
int ultimoPotOled = -1;
int potRawOled = 0;
int potPopupUltimaLettura = -1;
unsigned long potPopupUltimaVariazioneMs = 0;
bool potPopupInAttesa = false;
const int POT_POPUP_DELTA = 60;
const unsigned long POT_POPUP_SETTLE_MS = 3000UL;
const unsigned long OLED_POPUP_MS = 1800UL;

// Tre velocita' discrete: 1, 3 o 5 minuti, con potenziometro invertito.
// La corsa utile rilevata sull'hardware e' 0..680 (non 0..1023).
const unsigned long MIN_CYCLE_MS = 1UL * 60UL * 1000UL;
const unsigned long MID_CYCLE_MS = 3UL * 60UL * 1000UL;
const unsigned long MAX_CYCLE_MS = 5UL * 60UL * 1000UL;
const int POT_RAW_MAX = 680;
unsigned long durataCicloStabile = MIN_CYCLE_MS;
int potRawStabile = 0;

// Fasi in percentuale
const float P_TRAMONTO = 40.0f;
const float P_CREPU    = 50.0f;
const float P_NOTTE    = 55.0f;
const float P_ALBA     = 85.0f;
// ALBA occupa l'ultimo 15% del ciclo e termina direttamente nel nuovo GIORNO.

const unsigned long DEBOUNCE_MS = 20;
const unsigned long DEBUG_INTERVAL_MS = 5000UL;

// ============================================================
// STATO
// ============================================================

enum Fase {
  GIORNO,
  TRAMONTO,
  CREPUSCOLO,
  NOTTE,
  ALBA
};

// ============================================================
// SCHEDULAZIONE RELÈ
// ============================================================
// Ogni riga: { FASE, RELÈ, STATO, % DELLA FASE }.
// La tabella descrive eventi persistenti: quando un evento viene raggiunto,
// il relè mantiene lo stato fino al successivo evento che lo riguarda.
//
// Esempio attuale:
// - Grp_01_03 si accende al 30% del TRAMONTO.
// - Grp_01_03 si spegne al 50% della NOTTE.
//
// Per aggiungere la schedulazione definitiva sarà sufficiente modificare
// questo array. Le percentuali valide sono 0..100.
enum ReleNome : uint8_t {
  Grp_01_01 = 0, Grp_01_02, Grp_01_03, Grp_01_04,
  Grp_02_01,     Grp_02_02, Grp_02_03, Grp_02_04,
  Grp_03_01,     Grp_03_02, Grp_03_03, Grp_03_04,
  Grp_04_01,     Grp_04_02, Grp_04_03, Grp_04_04
};

struct EventoRele {
  Fase fase;
  ReleNome rele;
  bool acceso;
  uint8_t percentualeFase;
};

const EventoRele SCHEDULAZIONE_RELE[] = {
  { TRAMONTO, Grp_01_03, true,  30 },
  { NOTTE,    Grp_01_03, false, 50 }
};

const uint8_t NUM_EVENTI_RELE =
  sizeof(SCHEDULAZIONE_RELE) / sizeof(SCHEDULAZIONE_RELE[0]);

bool running = true;
bool testInCorso = false;
uint8_t testIndice = 0;
bool testEraInMarcia = false;
unsigned long testPausaMs = 0;

unsigned long cycleStartMs = 0;
unsigned long pauseStartedMs = 0;
unsigned long lastDebugMs = 0;

// Ultimi valori RGB realmente richiesti alle tre strisce.
// Servono anche per mostrarli sul display quando il ciclo viene messo in pausa.
uint8_t rgbCieloR = 0, rgbCieloG = 0, rgbCieloB = 0;
uint8_t rgbTramontoR = 0, rgbTramontoG = 0, rgbTramontoB = 0;
uint8_t rgbAlbaR = 0, rgbAlbaG = 0, rgbAlbaB = 0;

// debounce pulsanti
bool lastStartRead = HIGH, stableStart = HIGH;
bool lastNextRead  = HIGH, stableNext  = HIGH;
bool lastTestRead  = HIGH, stableTest  = HIGH;
unsigned long dbStartMs = 0, dbNextMs = 0, dbTestMs = 0;

// Feedback acustico semplice e non bloccante.
// Tutti i comandi (START/STOP, AVANTI, TEST e potenziometro) usano lo stesso bip.
const uint16_t BEEP_HZ = 900;
const uint16_t BEEP_MS = 90;
unsigned long buzzerFino = 0;
bool buzzerAttivo = false;
bool buzzerPrioritaComando = false;
int potBeepRiferimento = -1;
int potBeepUltimaLettura = -1;
unsigned long potUltimaVariazioneMs = 0;
bool potBeepInAttesa = false;
const int POT_BEEP_DELTA = 60;                 // circa 8% della corsa: ignora piccoli spostamenti/rumore
const int POT_BEEP_STABILITA_DELTA = 4;        // entro 4 punti ADC consideriamo il pot fermo
const unsigned long POT_BEEP_SETTLE_MS = 350UL; // bip solo 350 ms dopo l'ultima variazione

void buzzerBeep(bool comando = true) {
  if (!BUZZER_ENABLED) return;

  // I comandi fisici hanno priorita': il feedback del potenziometro
  // non puo' troncare o sostituire un bip START/STOP, AVANTI o TEST.
  if (!comando && buzzerAttivo && buzzerPrioritaComando) return;

  // Ripartenza esplicita: ogni comando riconosciuto ottiene un bip completo.
  noTone(PIN_BUZZER);
  tone(PIN_BUZZER, BEEP_HZ);
  buzzerFino = millis() + BEEP_MS;
  buzzerAttivo = true;
  buzzerPrioritaComando = comando;
}

void buzzerTick() {
  if (buzzerAttivo && (long)(millis() - buzzerFino) >= 0) {
    noTone(PIN_BUZZER);
    buzzerAttivo = false;
    buzzerPrioritaComando = false;
  }
}

void buzzerPotTick(int raw) {
  unsigned long now = millis();

  if (potBeepRiferimento < 0) {
    potBeepRiferimento = raw;
    potBeepUltimaLettura = raw;
    return;
  }

  // Segui il movimento reale del potenziometro, ignorando il normale rumore ADC.
  if (abs(raw - potBeepUltimaLettura) >= POT_BEEP_STABILITA_DELTA) {
    potBeepUltimaLettura = raw;
    potUltimaVariazioneMs = now;

    // Il bip viene armato solo dopo uno spostamento consistente.
    if (abs(raw - potBeepRiferimento) >= POT_BEEP_DELTA)
      potBeepInAttesa = true;
  }

  // Un solo bip quando la manopola e' rimasta ferma per qualche centinaio di ms.
  if (potBeepInAttesa && now - potUltimaVariazioneMs >= POT_BEEP_SETTLE_MS) {
    potBeepInAttesa = false;
    potBeepRiferimento = raw;
    potBeepUltimaLettura = raw;
    buzzerBeep(false);
  }
}

// ============================================================
// PWM
// ============================================================

// Correzione percettiva per le strisce RGB analogiche.
// La scenografia lavora 0..255 e analogWrite() resta PWM hardware a 8 bit.
// Applichiamo una curva gamma ~2.0 e arrotondiamo al gradino PWM piu' vicino.
// Nessun dithering temporale: evitiamo l'alternanza tra gradini alle basse luci.
const bool PWM_GAMMA = true;

int8_t pwmChannelIndex(uint8_t pin) {
  const uint8_t pins[9] = {
    PIN_CIELO_R, PIN_CIELO_G, PIN_CIELO_B,
    PIN_TRAMONTO_R, PIN_TRAMONTO_G, PIN_TRAMONTO_B,
    PIN_ALBA_R, PIN_ALBA_G, PIN_ALBA_B
  };
  for (uint8_t i = 0; i < 9; i++)
    if (pins[i] == pin) return i;
  return -1;
}

void pwmWrite(uint8_t pin, uint8_t value) {
  uint8_t out = value;

  if (PWM_GAMMA) {
    // Gamma 2.0 calcolata in fixed point; il risultato viene poi
    // arrotondato al gradino PWM hardware 8-bit piu' vicino.
    uint32_t squared = (uint32_t)value * (uint32_t)value;
    uint16_t pwm16 = (uint16_t)((squared * 4080UL + 32512UL) / 65025UL);
    uint8_t base = pwm16 >> 4;
    uint8_t frac = pwm16 & 0x0F;

    // Nessun dithering temporale: manteniamo la gamma e arrotondiamo
    // semplicemente al gradino PWM 8-bit piu' vicino.
    // Questo elimina l'alternanza tra gradini che sull'hardware reale
    // viene percepita come lampeggio alle bassissime luminosita'.
    if (frac >= 8 && base < 255) base++;
    out = base;
  }

  analogWrite(pin, PWM_INVERTED ? (255 - out) : out);
}

void setCielo(uint8_t r, uint8_t g, uint8_t b) {
  rgbCieloR = r; rgbCieloG = g; rgbCieloB = b;
  pwmWrite(PIN_CIELO_R, r);
  pwmWrite(PIN_CIELO_G, g);
  pwmWrite(PIN_CIELO_B, b);
}

void setTramonto(uint8_t r, uint8_t g, uint8_t b) {
  rgbTramontoR = r; rgbTramontoG = g; rgbTramontoB = b;
  pwmWrite(PIN_TRAMONTO_R, r);
  pwmWrite(PIN_TRAMONTO_G, g);
  pwmWrite(PIN_TRAMONTO_B, b);
}

void setAlba(uint8_t r, uint8_t g, uint8_t b) {
  rgbAlbaR = r; rgbAlbaG = g; rgbAlbaB = b;
  pwmWrite(PIN_ALBA_R, r);
  pwmWrite(PIN_ALBA_G, g);
  pwmWrite(PIN_ALBA_B, b);
}

// ============================================================
// STELLE WS2811
// ============================================================
// Effetto naturale: ogni notte viene generato un cielo diverso.
// Ogni notte vengono scelte casualmente 20 stelle su 50, con luminosita'
// massime differenti. Compaiono nel crepuscolo, restano attive di notte e
// scompaiono durante l'alba. Tutte le 20 hanno variazioni asincrone individuali.

uint8_t stellaLum[NUM_STELLE];
uint8_t stellaOrdine[NUM_STELLE];
bool stellaTwinkle[NUM_STELLE];
bool cieloGenerato = false;
Fase ultimaFaseStelle = GIORNO;

void generaCieloStellato() {
  // Ogni notte scegliamo casualmente solo 20 delle 50 stelle fisiche.
  // Le altre 30 restano completamente spente.
  for (uint16_t i = 0; i < NUM_STELLE; i++) {
    stellaLum[i] = random(22, 76); // luce volutamente tenue: niente effetto "lampadina"
    stellaOrdine[i] = i;
    stellaTwinkle[i] = false;
  }

  // Fisher-Yates su tutti i 50 pixel: i primi 20 saranno quelli attivi.
  for (int i = NUM_STELLE - 1; i > 0; i--) {
    int j = random(i + 1);
    uint8_t tmp = stellaOrdine[i];
    stellaOrdine[i] = stellaOrdine[j];
    stellaOrdine[j] = tmp;
  }

  // Tutte le 20 stelle attive ricevono il comportamento variabile.
  // Il piccolo shuffle assegna il flag alle stelle gia' selezionate casualmente;
  // STELLE_TREMOLANTI coincide attualmente con STELLE_ATTIVE, quindi sono tutte.
  uint8_t candidati[STELLE_ATTIVE];
  for (uint8_t i = 0; i < STELLE_ATTIVE; i++) candidati[i] = i;
  for (int i = STELLE_ATTIVE - 1; i > 0; i--) {
    int j = random(i + 1);
    uint8_t tmp = candidati[i];
    candidati[i] = candidati[j];
    candidati[j] = tmp;
  }
  for (uint8_t n = 0; n < STELLE_TREMOLANTI; n++)
    stellaTwinkle[stellaOrdine[candidati[n]]] = true;

  cieloGenerato = true;
}

void mostraStelle(float livello) {
  livello = constrain(livello, 0.0f, 1.0f);
  stelle.clear();

  // Durante il crepuscolo entrano progressivamente le 20 stelle scelte;
  // durante l'alba scompaiono progressivamente. Mai piu' di 20 accese.
  uint8_t visibili = (uint8_t)(livello * STELLE_ATTIVE + 0.5f);
  if (visibili > STELLE_ATTIVE) visibili = STELLE_ATTIVE;

  for (uint8_t pos = 0; pos < visibili; pos++) {
    uint8_t i = stellaOrdine[pos];
    float locale = livello * STELLE_ATTIVE - pos;
    locale = constrain(locale, 0.0f, 1.0f);

    uint16_t v = (uint16_t)(stellaLum[i] * locale);

    // Ogni stella attiva segue autonomamente un ciclo di luminosita':
    // livello pieno -> dissolvenza a zero -> pausa spenta -> riaccensione.
    // Durate e offset differenti evitano che le 20 stelle si muovano insieme.
    if (stellaTwinkle[i] && v > 5) {
      // Durata pseudo-casuale e stabile per ogni pixel: circa 6,4-12,2 s.
      // Rev037: raddoppiata per rendere accensione/spegnimento piu' lento dal vero.
      // Anche l'offset e' diverso per ogni stella, cosi' partono vicine ma non insieme
      // e col tempo si sfasano sempre di piu'.
      const unsigned long periodo = 6400UL + ((unsigned long)(i * 37U) % 30UL) * 200UL;
      const unsigned long offset = ((unsigned long)(i * 173U) % 900UL);
      const unsigned long faseMs = (millis() + offset) % periodo;
      const unsigned long pTw = (faseMs * 100UL) / periodo;
      uint8_t fattore = 100;

      if (pTw < 45) {
        fattore = 100;                              // piena luminosita'
      } else if (pTw < 55) {
        fattore = (uint8_t)((55UL - pTw) * 10UL);  // 100 -> 0
      } else if (pTw < 80) {
        fattore = 0;                                // SPENTA per il 25% del ciclo
      } else if (pTw < 90) {
        fattore = (uint8_t)((pTw - 80UL) * 10UL);  // 0 -> 100
      } else {
        fattore = 100;
      }

      // A fattore zero scriviamo esplicitamente nero sul pixel.
      if (fattore == 0) {
        v = 0;
      } else {
        v = (v * fattore) / 100U;
      }
    }

    // Bianco caldo tenue.
    stelle.setPixelColor(i, stelle.Color(
      (uint8_t)v,
      (uint8_t)((v * 72U) / 100U),
      (uint8_t)((v * 38U) / 100U)
    ));
  }
  // NeoPixel disabilita gli interrupt durante la trasmissione.
  // Limitiamo il refresh a 50 Hz per non alterare millis()/Timer0.
  static unsigned long ultimoShowStelleUs = 0;
  unsigned long adessoUs = micros();
  if ((unsigned long)(adessoUs - ultimoShowStelleUs) >= 20000UL) {
    stelle.show();
    ultimoShowStelleUs = adessoUs;
  }
}

void setStelle(uint8_t value) {
  if (!cieloGenerato) generaCieloStellato();
  mostraStelle(value / 255.0f);
}

void tuttoSpento() {
  setCielo(0, 0, 0);
  setTramonto(0, 0, 0);
  setAlba(0, 0, 0);
  setStelle(0);
  casette.clear();
  casette.show();
}

// ============================================================
// TEMPO / POTENZIOMETRO
// ============================================================

unsigned long durataDaRaw(int raw) {
  raw = constrain(raw, 0, POT_RAW_MAX);

  // Il potenziometro e' cablato al contrario: raw=0 e' il massimo logico.
  // Suddivisione in tre intervalli, inclusi entrambi gli estremi:
  // raw fisico 454..680 -> 1 min; 227..453 -> 3 min; 0..226 -> 5 min.
  int rawInvertito = POT_RAW_MAX - raw;
  if (rawInvertito < (POT_RAW_MAX + 1) / 3) return MIN_CYCLE_MS;
  if (rawInvertito < 2 * (POT_RAW_MAX + 1) / 3) return MID_CYCLE_MS;
  return MAX_CYCLE_MS;
}

unsigned long durataCiclo() {
  // La durata usata dal ciclo NON segue il rumore istantaneo dell'ADC.
  return durataCicloStabile;
}

void stampaDurataOled(unsigned long durata) {
  unsigned long secondi = (durata + 500UL) / 1000UL;
  unsigned int mm = secondi / 60UL;
  unsigned int ss = secondi % 60UL;
  if (mm < 10) display.print('0');
  display.print(mm);
  display.print(':');
  if (ss < 10) display.print('0');
  display.print(ss);
}

float percentualeCiclo(unsigned long durata) {
  unsigned long riferimento = running ? millis() : pauseStartedMs;
  unsigned long elapsed = riferimento - cycleStartMs;
  elapsed %= durata;
  return (elapsed * 100.0f) / durata;
}

float progresso(float p, float inizio, float fine) {
  if (fine <= inizio) return 0.0f;
  return constrain((p - inizio) / (fine - inizio), 0.0f, 1.0f);
}

uint8_t interpola8(uint8_t da, uint8_t a, float t) {
  t = constrain(t, 0.0f, 1.0f);
  return (uint8_t)(da + ((float)a - da) * t);
}

// ============================================================
// FASI
// ============================================================

Fase faseDaPercentuale(float p) {
  if (p < P_TRAMONTO) return GIORNO;
  if (p < P_CREPU)    return TRAMONTO;
  if (p < P_NOTTE)    return CREPUSCOLO;
  if (p < P_ALBA)     return NOTTE;
  return ALBA;
}

const char* nomeFase(Fase f) {
  switch (f) {
    case GIORNO:        return "GIORNO";
    case TRAMONTO:      return "TRAMONTO";
    case CREPUSCOLO:    return "CREPUSCOLO";
    case NOTTE:         return "NOTTE";
    case ALBA:          return "ALBA";
  }
  return "?";
}

float inizioFase(Fase f) {
  switch (f) {
    case GIORNO:        return 0.0f;
    case TRAMONTO:      return P_TRAMONTO;
    case CREPUSCOLO:    return P_CREPU;
    case NOTTE:         return P_NOTTE;
    case ALBA:          return P_ALBA;
  }
  return 0.0f;
}

Fase faseSuccessiva(Fase f) {
  switch (f) {
    case GIORNO:        return TRAMONTO;
    case TRAMONTO:      return CREPUSCOLO;
    case CREPUSCOLO:    return NOTTE;
    case NOTTE:         return ALBA;
    case ALBA:          return GIORNO;
  }
  return GIORNO;
}

float fineFase(Fase f) {
  switch (f) {
    case GIORNO:     return P_TRAMONTO;
    case TRAMONTO:   return P_CREPU;
    case CREPUSCOLO: return P_NOTTE;
    case NOTTE:      return P_ALBA;
    case ALBA:       return 100.0f;
  }
  return 100.0f;
}

uint8_t indiceFase(Fase f) {
  return (uint8_t)f;
}

void scriviRele(uint8_t indice, bool acceso) {
  if (indice >= 16) return;
  digitalWrite(PIN_RELE[indice],
               acceso ? (RELE_ACTIVE_LOW ? LOW : HIGH)
                      : (RELE_ACTIVE_LOW ? HIGH : LOW));
}
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
void loop() {

  buzzerTick();

  // ----- comandi fisici -----

  if (pulsantePremuto(PIN_START,
                      lastStartRead, stableStart, dbStartMs)) {
    toggleStartStop();
  }

  if (pulsantePremuto(PIN_NEXT,
                      lastNextRead, stableNext, dbNextMs)) {
    if (!testInCorso) faseAvanti();
  }

  if (pulsantePremuto(PIN_TEST,
                      lastTestRead, stableTest, dbTestMs)) {
    testUscite();
  }

  // ----- ciclo scenografico -----

  if (!testInCorso) {
    unsigned long durata = durataCiclo();
    float p = percentualeCiclo(durata);

    int potNow = analogRead(PIN_POT);
    int potNowLimitato = constrain(potNow, 0, POT_RAW_MAX);

    // Attendi la stabilizzazione prima di cambiare scaglione.
    // Anche uno spostamento minimo oltre una soglia deve essere rilevato.
    if (ultimoPotOled < 0) {
      ultimoPotOled = potRawStabile;
      potPopupUltimaLettura = potNowLimitato;
    }
    if (abs(potNowLimitato - potPopupUltimaLettura) >= POT_BEEP_STABILITA_DELTA) {
      potPopupUltimaLettura = potNowLimitato;
      potPopupUltimaVariazioneMs = millis();
    }
    // Non usare una soglia RAW fissa: impedirebbe di riconoscere
    // il passaggio tra due scaglioni vicino al loro confine.
    potPopupInAttesa = (durataDaRaw(potNowLimitato) != durataCicloStabile);

    if (potPopupInAttesa &&
        millis() - potPopupUltimaVariazioneMs >= POT_POPUP_SETTLE_MS) {
      potPopupInAttesa = false;
      // Mantieni la stessa posizione percentuale della scena quando cambia
      // la durata totale: cambiare velocita' non deve far saltare fase.
      unsigned long vecchiaDurata = durataCicloStabile;
      unsigned long riferimento = running ? millis() : pauseStartedMs;
      unsigned long elapsedVecchio = (riferimento - cycleStartMs) % vecchiaDurata;
      float posizione = (float)elapsedVecchio / (float)vecchiaDurata;

      potRawStabile = potNowLimitato;
      durataCicloStabile = durataDaRaw(potRawStabile);
      unsigned long nuovoElapsed = (unsigned long)(posizione * durataCicloStabile + 0.5f);
      cycleStartMs = riferimento - nuovoElapsed;
      ultimoPotOled = potRawStabile;
      potRawOled = potRawStabile;
      oledMostraPopup(OLED_VELOCITA);
    }

    buzzerPotTick(potNowLimitato);

    // Se lo scaglione e' cambiato, usa subito la durata e la
    // posizione ricalcolate anche per scena, rele' e display.
    durata = durataCiclo();
    p = percentualeCiclo(durata);
    aggiornaScena(p);
    aggiornaReleSchedulati(p);
    aggiornaOled(durata, p);

    // ----- diagnostica -----
    if (millis() - lastDebugMs >= DEBUG_INTERVAL_MS) {
      lastDebugMs = millis();
      stampaStato(durata, p);
    }
  }
}

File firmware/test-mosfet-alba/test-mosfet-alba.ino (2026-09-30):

/*
  TEST A/B MOSFET RGB - Arduino Mega 2560
  ---------------------------------------
  Confronto simultaneo, a parita' di algoritmo:
    TRAMONTO = vecchia scheda MOSFET: D7, D11, D12
    ALBA     = nuova scheda MOSFET:   D44, D45, D46
    A0       = potenziometro
    D23      = AVANTI -> modalita' SOLO ROSSO
    D22      = START  -> modalita' RGB COMPLETO
    OLED I2C 128x64, 0x3C

  Il potenziometro varia continuamente:
    SOLO ROSSO: rosso tenue -> rosso pieno
    RGB: arancio tenue -> bianco caldo luminoso

  Entrambe le strisce ricevono SEMPRE gli stessi valori logici e lo stesso
  algoritmo: PWM hardware 8 bit + gamma 2.0, SENZA dithering temporale.
*/

#include <Arduino.h>
#include <Wire.h>
#include <Adafruit_GFX.h>
#include <Adafruit_SSD1306.h>

const uint8_t PIN_OLD_R = 7;
const uint8_t PIN_OLD_G = 11;
const uint8_t PIN_OLD_B = 12;
const uint8_t PIN_NEW_R = 44;
const uint8_t PIN_NEW_G = 45;
const uint8_t PIN_NEW_B = 46;

const uint8_t PIN_START = 22;
const uint8_t PIN_NEXT  = 23;
const uint8_t PIN_POT   = A0;

const int POT_RAW_MAX = 680;
const bool PWM_INVERTED = false;

const uint8_t OLED_ADDR = 0x3C;
Adafruit_SSD1306 display(128, 64, &Wire, -1);
bool oledPresente = false;

enum Modalita { SOLO_ROSSO, RGB_COMPLETO };
Modalita modalita = SOLO_ROSSO;

// Estremi logici RGB del test completo.
const uint8_t LOW_R  = 24;
const uint8_t LOW_G  = 5;
const uint8_t LOW_B  = 0;
const uint8_t HIGH_R = 255;
const uint8_t HIGH_G = 185;
const uint8_t HIGH_B = 95;

uint8_t gamma2(uint8_t value) {
  uint32_t squared = (uint32_t)value * value;
  return (uint8_t)((squared * 255UL + 32512UL) / 65025UL);
}

void pwmWrite(uint8_t pin, uint8_t logical) {
  uint8_t physical = gamma2(logical);
  analogWrite(pin, PWM_INVERTED ? 255 - physical : physical);
}

uint8_t interpola(uint8_t a, uint8_t b, uint16_t x) {
  return a + ((long)(b - a) * x + 500L) / 1000L;
}

void scriviEntrambe(uint8_t r, uint8_t g, uint8_t b) {
  // Stessi identici valori, nello stesso loop, ai vecchi e ai nuovi MOSFET.
  pwmWrite(PIN_OLD_R, r);
  pwmWrite(PIN_NEW_R, r);
  pwmWrite(PIN_OLD_G, g);
  pwmWrite(PIN_NEW_G, g);
  pwmWrite(PIN_OLD_B, b);
  pwmWrite(PIN_NEW_B, b);
}

bool pressione(uint8_t pin) {
  static bool precStart = HIGH, precNext = HIGH;
  bool ora = digitalRead(pin);
  bool &prec = (pin == PIN_START) ? precStart : precNext;
  bool evento = (prec == HIGH && ora == LOW);
  prec = ora;
  return evento;
}

void setup() {
  const uint8_t uscite[] = {PIN_OLD_R,PIN_OLD_G,PIN_OLD_B,PIN_NEW_R,PIN_NEW_G,PIN_NEW_B};
  for (uint8_t i=0; i<6; i++) {
    pinMode(uscite[i], OUTPUT);
    analogWrite(uscite[i], 0);
  }
  pinMode(PIN_START, INPUT_PULLUP);
  pinMode(PIN_NEXT, INPUT_PULLUP);

  Serial.begin(115200);
  Wire.begin();
#if defined(WIRE_HAS_TIMEOUT)
  Wire.setWireTimeout(25000UL, true);
#endif
  Wire.beginTransmission(OLED_ADDR);
  if (Wire.endTransmission() == 0)
    oledPresente = display.begin(SSD1306_SWITCHCAPVCC, OLED_ADDR);
}

void loop() {
  static int filtrato = -1;
  static unsigned long ultimoOled = 0;
  static unsigned long ultimoTasto = 0;

  if (millis() - ultimoTasto > 180) {
    if (pressione(PIN_NEXT)) {
      modalita = SOLO_ROSSO;
      ultimoTasto = millis();
    }
    if (pressione(PIN_START)) {
      modalita = RGB_COMPLETO;
      ultimoTasto = millis();
    }
  }

  int raw = constrain(analogRead(PIN_POT), 0, POT_RAW_MAX);
  if (filtrato < 0) filtrato = raw;
  filtrato = (filtrato * 7 + raw) / 8;

  // Potenziometro fisicamente invertito: raw basso = luminosita' alta.
  int invertito = POT_RAW_MAX - filtrato;
  uint16_t x = (uint32_t)invertito * 1000UL / POT_RAW_MAX;
  uint32_t xx = x;
  uint16_t smooth = (uint16_t)((xx * xx * (3000UL - 2UL * xx)) / 1000000UL);

  uint8_t r, g, b;
  if (modalita == SOLO_ROSSO) {
    // Parte da un rosso logico basso ma visibile e arriva al 100%.
    r = interpola(24, 255, smooth);
    g = 0;
    b = 0;
  } else {
    r = interpola(LOW_R, HIGH_R, smooth);
    g = interpola(LOW_G, HIGH_G, smooth);
    b = interpola(LOW_B, HIGH_B, smooth);
  }

  scriviEntrambe(r, g, b);

  if (millis() - ultimoOled >= 100) {
    ultimoOled = millis();
    uint8_t pr=gamma2(r), pg=gamma2(g), pb=gamma2(b);

    Serial.print(modalita == SOLO_ROSSO ? F("ROSSO") : F("RGB"));
    Serial.print(F(" A0=")); Serial.print(filtrato);
    Serial.print(F(" RGB=")); Serial.print(r); Serial.print(',');
    Serial.print(g); Serial.print(','); Serial.print(b);
    Serial.print(F(" PWM=")); Serial.print(pr); Serial.print(',');
    Serial.print(pg); Serial.print(','); Serial.println(pb);

    if (oledPresente) {
      display.clearDisplay();
      display.setTextColor(SSD1306_WHITE);
      display.setTextSize(1);
      display.setCursor(0,0); display.print(F("TEST A/B MOSFET"));
      display.setCursor(0,13);
      display.print(modalita == SOLO_ROSSO ? F("AVANTI: SOLO ROSSO") : F("START: RGB COMPLETO"));
      display.setCursor(0,27); display.print(F("A0 ")); display.print(filtrato);
      display.print(F("  ")); display.print((smooth+5)/10); display.print('%');
      display.setCursor(0,40); display.print(F("RGB "));
      display.print(r); display.print(','); display.print(g); display.print(','); display.print(b);
      display.setCursor(0,53); display.print(F("PWM "));
      display.print(pr); display.print(','); display.print(pg); display.print(','); display.print(pb);
      display.display();
    }
  }

  delay(5);
}

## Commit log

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2026-09-23 Fix common-positive RGB strip wiring documentation
2026-09-23 Reference corrected clean wiring diagram
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2026-09-24 Fix OLED helper declaration order for Arduino build
    [PSN-Presepe.ino]
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2026-09-25 Correct stale firmware comments without changing logic
    [PSN-Presepe.ino]
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2026-09-25 Fix relay test offset and clean test diagnostics
    [PSN-Presepe.ino]
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2026-09-25 Add optional boot melody buzzer on D6 (rev014)
    [PSN-Presepe.ino]
2026-09-25 Add non-blocking buzzer UI feedback (rev017)
    [PSN-Presepe.ino]
2026-09-25 Complete buzzer feedback for test exit
    [PSN-Presepe.ino]
2026-09-25 Simplify UI buzzer feedback to single beep (rev018)
    [PSN-Presepe.ino]
2026-09-25 Fix boot melody duration synchronization (rev019)
    [PSN-Presepe.ino]
2026-09-25 Keep boot duration constant minimal and correct
    [PSN-Presepe.ino]
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2026-09-25 Debounce potentiometer buzzer after large settled changes (rev021)
    [PSN-Presepe.ino]
2026-09-25 Prioritize reliable command buzzer feedback (rev022)
    [PSN-Presepe.ino]
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2026-09-27 Stabilize potentiometer duration and show MM:SS on OLED (rev034)
    [PSN-Presepe.ino]
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2026-09-27 Experiment with gamma corrected RGB PWM dithering
    [PSN-Presepe.ino]
2026-09-27 Fix cycle timing controls and move casette to D8
    [PSN-Presepe.ino]
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2026-09-28 Invert potentiometer direction in software
    [PSN-Presepe.ino]
2026-09-28 Use three discrete inverted potentiometer speeds at boot and runtime
    [PSN-Presepe.ino]
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2026-09-30 Add functional KiCad schematic source
    [PSN-Presepe-Mega.sch]
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2026-09-30 Freeze approved Rev A shield interfaces
    [PSN-Presepe-Mega.sch]
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2026-09-30 Add initial Rev A KiCad PCB outline
    [PSN-Presepe-Mega.kicad_pcb]
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2026-09-30 Place 16 G5Q relay footprints on Rev A PCB
    [PSN-Presepe-Mega.kicad_pcb]
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2026-09-30 Place 16 COM NO NC terminal blocks
    [PSN-Presepe-Mega.kicad_pcb]
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2026-09-30 Place Mega 2560 R3 shield footprint on carrier
    [PSN-Presepe-Mega.kicad_pcb]
2026-09-30 Place Rev A low-voltage components and terminals
    [PSN-Presepe-Mega.kicad_pcb]
2026-09-30 Define Rev A control nets and correct ULN2803 footprints
    [PSN-Presepe-Mega.kicad_pcb]
2026-09-30 Bind Mega control signals to MOSFETs and external interfaces
    [PSN-Presepe-Mega.kicad_pcb]
2026-09-30 Wire ULN2803 drivers to 16 relay coils
    [PSN-Presepe-Mega.kicad_pcb]
2026-09-30 Complete Rev A power and lighting nets
    [PSN-Presepe-Mega.kicad_pcb]
2026-09-30 Place potentiometer buzzer and MOSFET gate passives
    [PSN-Presepe-Mega.kicad_pcb]
2026-09-30 Complete pot buzzer gate networks and relay filtering
    [PSN-Presepe-Mega.kicad_pcb]
2026-09-30 Refine Rev A placement and isolation zoning
    [PSN-Presepe-Mega.kicad_pcb]
2026-09-30 Repair pad syntax and start SELV power routing
    [PSN-Presepe-Mega.kicad_pcb]
2026-09-30 Restore Mega footprint and correct relay isolation zoning
    [PSN-Presepe-Mega.kicad_pcb]
2026-09-30 Route main SELV power and ground trunks
    [PSN-Presepe-Mega.kicad_pcb]
2026-09-30 Route low-current Mega control signals
    [PSN-Presepe-Mega.kicad_pcb]
2026-09-30 Move relay terminals to outward-facing PCB edges
    [PSN-Presepe-Mega.kicad_pcb]
2026-09-30 Align all low-voltage terminals to outward PCB edge
    [PSN-Presepe-Mega.kicad_pcb]
2026-09-30 Add MOSFET heatsink clearance and thermal keep-out
    [PSN-Presepe-Mega.kicad_pcb]
2026-09-30 Reposition and route MOSFET gate networks
    [PSN-Presepe-Mega.kicad_pcb]
2026-09-30 Assign verified G5Q relay contact nets
    [PSN-Presepe-Mega.kicad_pcb]
2026-09-30 Enlarge PCB and increase relay wiring clearance
    [PSN-Presepe-Mega.kicad_pcb]
2026-09-30 Reflow SELV components for enlarged PCB
    [PSN-Presepe-Mega.kicad_pcb]
2026-09-30 Rebuild clean KiCad PCB structure from validated footprints
    [PSN-Presepe-Mega.kicad_pcb]
2026-09-30 Route validated local MOSFET gate and ground network
    [PSN-Presepe-Mega.kicad_pcb]
2026-09-30 Route 12V ground and relay coil power
    [PSN-Presepe-Mega.kicad_pcb]
2026-09-30 Route Mega relay controls and low-voltage power buses
    [PSN-Presepe-Mega.kicad_pcb]
2026-09-30 Connect Mega 5V and ground power nets
    [PSN-Presepe-Mega.kicad_pcb]
2026-09-30 Route low-voltage controls and RGB PWM signals
    [PSN-Presepe-Mega.kicad_pcb]
2026-09-30 Route RGB load outputs and power filtering
    [PSN-Presepe-Mega.kicad_pcb]
2026-09-30 Increase right-edge relay terminal board margins
    [PSN-Presepe-Mega.kicad_pcb]
2026-09-30 Route isolated relay COM NO NC contact networks
    [PSN-Presepe-Mega.kicad_pcb]
2026-09-30 Add terminal connection labels to PCB silkscreen
    [PSN-Presepe-Mega.kicad_pcb]
2026-09-30 Replace obsolete isolation line with relay contact zone warnings
    [PSN-Presepe-Mega.kicad_pcb]
2026-09-30 Reset conflicting SELV routes for clean reroute
    [PSN-Presepe-Mega.kicad_pcb]
2026-09-30 Reset draft routing after geometric conflict audit
    [PSN-Presepe-Mega.kicad_pcb]
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2026-09-30 Add six M3 mechanical mounting holes
    [PSN-Presepe-Mega.kicad_pcb]
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2026-09-30 Move mounting holes clear of terminal blocks
    [PSN-Presepe-Mega.kicad_pcb]
2026-09-30 Add relay COM and power polarity silkscreen markers
    [PSN-Presepe-Mega.kicad_pcb]
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2026-09-30 Fix KiCad 9 Gerber and drill export commands
2026-09-30 Fix malformed pad layer and net syntax
    [PSN-Presepe-Mega.kicad_pcb]
2026-09-30 Fix malformed Mega pad net placement
    [PSN-Presepe-Mega.kicad_pcb]
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2026-09-30 Fix Mega VIN pad syntax
    [PSN-Presepe-Mega.kicad_pcb]
2026-09-30 Repair corrupted Mega VIN and embedded net block
    [PSN-Presepe-Mega.kicad_pcb]
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2026-09-30 Remove legacy footprint header from embedded Mega
    [PSN-Presepe-Mega.kicad_pcb]
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2026-09-30 Fix KiCad 9 board layer table IDs
    [PSN-Presepe-Mega.kicad_pcb]
2026-09-30 Resolve ULN decoupling and mounting-hole placement collisions
    [PSN-Presepe-Mega.kicad_pcb]
2026-09-30 Correct Omron G5Q-1 SPDT footprint geometry
2026-09-30 Apply corrected G5Q geometry to all 16 relays
    [PSN-Presepe-Mega.kicad_pcb]
2026-09-30 Separate ULN decoupling capacitors from driver pads
    [PSN-Presepe-Mega.kicad_pcb]
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2026-09-30 Mirror legacy Mega back-silkscreen marker
    [PSN-Presepe-Mega.kicad_pcb]
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2026-09-30 Correct G5Q-1 SPDT footprint pin geometry
2026-09-30 Correct all G5Q relay contact pin geometry and nets
    [PSN-Presepe-Mega.kicad_pcb]
2026-09-30 Raise PCB silkscreen text to DRC minimum height
    [PSN-Presepe-Mega.kicad_pcb]
2026-09-30 Correct documented G5Q-1 contact pin mapping
2026-09-30 Move component references off fabrication silkscreen
    [PSN-Presepe-Mega.kicad_pcb]
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2026-09-30 Fix Omron G5Q relay NC and COM net assignments
    [PSN-Presepe-Mega.kicad_pcb]
2026-09-30 Regenerate pin-net audit after G5Q correction
2026-09-30 Document corrected G5Q-1 relay pinout
2026-09-30 Repair relay net IDs after COM NC correction
    [PSN-Presepe-Mega.kicad_pcb]
2026-09-30 Refresh pin net audit after relay contact correction
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2026-09-30 Clean relay and mounting-hole silkscreen warnings
    [PSN-Presepe-Mega.kicad_pcb]
2026-09-30 Restore verified G5Q contact net mapping on current PCB
    [PSN-Presepe-Mega.kicad_pcb]
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2026-09-30 Correct G5Q pin mapping in pin-net audit
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2026-09-30 Speed PCB CI by skipping unused KiCad 3D packages
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2026-09-30 Move relay safety notes to clear silkscreen area
    [PSN-Presepe-Mega.kicad_pcb]
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2026-09-30 Clear final silkscreen text overlap
    [PSN-Presepe-Mega.kicad_pcb]
2026-09-30 Resolve final silkscreen text overlap
    [PSN-Presepe-Mega.kicad_pcb]
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2026-09-30 Gate PCB CI on DRC errors while retaining warning report
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2026-10-01 Remove redundant relay warning causing silk overlaps
    [PSN-Presepe-Mega.kicad_pcb]
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2026-10-01 Use two vias to resolve button routing topology
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2026-10-01 Promote first DRC-approved button routes
    [PSN-Presepe-Mega.kicad_pcb]
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2026-10-01 Promote DRC-clean OLED I2C routing
    [PSN-Presepe-Mega.kicad_pcb]
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2026-10-01 Promote DRC-clean OLED I2C routes
    [PSN-Presepe-Mega.kicad_pcb]
2026-10-01 Remove duplicate promoted OLED segments
    [PSN-Presepe-Mega.kicad_pcb]
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2026-10-01 Promote clean A0 potentiometer routing
    [PSN-Presepe-Mega.kicad_pcb]
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2026-10-01 Promote DRC-clean local MOSFET gate routing
    [PSN-Presepe-Mega.kicad_pcb]
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2026-10-01 Fix absolute pad transform for rotated KiCad footprints
2026-10-01 Retest relay-1 coil using corrected rotated-pad coordinate
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2026-10-01 Fix rotated footprint pad coordinate transform
2026-10-01 Retest relay coil route with corrected rotated pad coordinate
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2026-10-01 Guard corrected rotated relay-pad geometry in CI
2026-10-01 Promote DRC-clean relay-1 coil route
    [PSN-Presepe-Mega.kicad_pcb]
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2026-10-01 Test K2 coil-low route from corrected relay geometry
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2026-10-01 WIP candidate: increase K13 relay-pad clearance
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2026-10-01 Promote KiCad-validated K15 route with K9 K12 repack
    [PSN-Presepe-Mega.kicad_pcb]
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2026-10-01 Promote KiCad-validated K16 route with K11 K14 repack
    [PSN-Presepe-Mega.kicad_pcb]
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2026-10-01 Remove D30 route pending full-DRC-clean redesign
    [PSN-Presepe-Mega.kicad_pcb]
2026-10-01 Fix D29 clearance to D28
    [PSN-Presepe-Mega.kicad_pcb]
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2026-10-01 Adjust D29 escape via for full DRC clearance
    [PSN-Presepe-Mega.kicad_pcb]
2026-10-01 Fix KiCad 9 unconnected-pad parsing in autoroute comparison
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2026-10-01 Fix KiCad header net parser syntax
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2026-10-01 Fix multiline KiCad sanity regex literals
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2026-10-01 Fix multiline targeted workflow path filter
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2026-10-01 Fix final ALBA_B via clearance
    [PSN-Presepe-Mega.kicad_pcb]
2026-10-01 Increase ALBA_B clearance with 0.6 mm via
    [PSN-Presepe-Mega.kicad_pcb]
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2026-10-01 Batch route short relay contact nets
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2026-10-01 Fix relay batch number parsing
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2026-10-01 Fix relay candidate board serialization
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2026-10-01 Run corrected relay batch candidates
2026-10-01 Correct relay candidate escape depth
2026-10-01 Execute corrected relay serialization
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2026-10-01 Relax single-layer relay search to manufacturable clearance
2026-10-01 Return relay batch to two-layer A-star with tighter clearance
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2026-10-01 Expose A-star relay failure diagnostics
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2026-10-01 Fix KiCad rotated pad coordinate transform
2026-10-01 Fix rotated footprint obstacle coordinates
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2026-10-01 Fix relay promotion gate category parser
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2026-10-01 Fix final relay sweep KiCad record escaping
2026-10-01 Fix footprint pad rotation in obstacle map
2026-10-01 Validate corrected footprint obstacle geometry
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2026-10-01 Fix relay sweep indentation and pad rotation
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2026-10-01 Validate selective removal of clearance-failing relay nets
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2026-10-01 Route all remaining relay contacts cumulatively with project clearance
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2026-10-01 Use correct KiCad pad transform for relay endpoints
2026-10-01 Inflate relay obstacles for raster-safe 1mm clearance
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2026-10-02 Search final six relay contacts on finer clearance-safe grid
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2026-10-02 Fix cumulative relay promotion category parser
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2026-10-02 Run fixed dual-layer relay routing
2026-10-02 Trigger corrected dual-layer relay search
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2026-10-02 Add standards-plan clearance fallback for relay routes
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2026-10-02 Fail fast on PCB router syntax errors
2026-10-02 Add standards-plan clearance fallback for stubborn relays
2026-10-02 Compensate relay path search for track-width clearance
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2026-10-02 Fix large PCB DRC category parser
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2026-10-02 Fix KiCad segment newline escaping in large autorouter
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2026-10-03 Fix PCB size sweep workflow trigger parsing
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2026-10-03 Add 6mm relay contact to SELV clearance rule
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2026-10-03 Fix clean PCB generator syntax
2026-10-03 Fix clean board generator on current dev head
2026-10-03 Repair clean board generator newline correctly
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2026-10-03 Fail CI on every unexpected KiCad DRC category
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2026-10-03 Resolve PCB courtyard placement conflicts
    [PSN-Presepe-Mega.kicad_pcb]
2026-10-03 Move H2 away from relay terminal clearance zone
    [PSN-Presepe-Mega.kicad_pcb]
2026-10-03 Print full final DRC details for deterministic fixes
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2026-10-03 Fix terminal visibility checker for KiCad 10 API
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2026-10-03 Add terminal function and relay channel silkscreen labels
    [PSN-Presepe-Mega.kicad_pcb]
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2026-10-03 Fix terminal silkscreen parser for multiple user texts
2026-10-03 Fix fp_text regex escaping in silkscreen gate
2026-10-03 Replace fragile silkscreen regex with structural parser
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2026-10-03 Fix KiCad10 manufacturing export and add BOM CPL
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2026-10-03 Fix manufacturing Gerber extension validation
2026-10-03 Fix POSIX shell Gerber validation
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2026-10-03 Fix KiCad 10 solder mask layer names
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2026-10-03 Add validated Rev-A PCB manufacturing release [skip ci]
    [BOM.csv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]
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2026-10-03 Expand PCB outline to 300x180mm for production-width routing
    [PSN-Presepe-Mega.kicad_pcb]
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2026-10-03 Restore 280x170 outline for targeted K10 routing fix
    [PSN-Presepe-Mega.kicad_pcb]
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2026-10-03 Move lower mounting hole clear of J1 terminal silkscreen
    [PSN-Presepe-Mega.kicad_pcb]
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2026-10-03 Inject fixed 3mm GND backbone into Specctra DSN
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2026-10-03 Bypass MOSFET GND spine with clearance-safe 3mm route
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2026-10-03 Fix KiCad 10 solder-mask Gerber export syntax
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2026-10-03 Add validated Rev-B PCB manufacturing release [skip ci]
    [BOM.csv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]
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2026-10-03 Fix relay isolation audit geometry validation
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2026-10-03 Fix Rev-B schematic generator syntax
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2026-10-03 Fix PCB validation workflow YAML
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2026-10-03 Add KiCad 10 real schematic parser fixture
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2026-10-03 Prevent Rev-B schematic pin and net-label overlaps
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
